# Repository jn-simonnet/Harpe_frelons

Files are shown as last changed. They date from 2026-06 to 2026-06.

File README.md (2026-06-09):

# 🐝⚡ Harpe anti-frelons asiatiques

> Conception, fabrication maison et expérimentation en conditions réelles d'une **harpe électrique anti-frelons asiatiques** — une alternative économique et durable aux dispositifs du commerce, alimentée au solaire et optionnellement connectée (LoRaWAN).

*Documentation présentée à l'atelier **Naturapi** du 27 juin 2026.*
*© J.-N. Simonnet, 2026 — Licence : [GNU GPL v3](LICENSE).*

---

## ⚡ En bref

- **Principe** : deux plans de fils inox verticaux portés à ~2 000 V. Pas de 25 mm — inférieur à l'envergure du frelon (≈ 36–40 mm), supérieur à celle de l'abeille (16 mm) : un filtre sélectif.
- **Tout au solaire, sans batterie** : ni le frelon ni l'abeille ne volent la nuit.
- **Économique** : ~200 € en autoconstruction contre 292 € à 479 € pour un kit du commerce.
- **Durable** : pièces imprimées en 3D, isolation et vernis marin soignés pour résister à la pluie et aux UV.
- **Connectée (option)** : suivi à distance de l'activité du frelon et de l'efficacité via LoRaWAN.

---

## 📖 Par où commencer

👉 **Commencez par lire [`harpe_resume-pres_naturapi.pdf`](harpe_resume-pres_naturapi.pdf).**

Ce résumé de 3 pages présente l'ensemble du projet : principe, recommandations des GDSA, fabrication, précautions d'installation et premiers résultats. Les autres documents en détaillent chacun un aspect (mécanique, électronique, support solaire, essai de terrain, nomenclature chiffrée).

---

## 📂 Contenu du dépôt

| Ordre | Fichier | Type | Description |
|:---:|---|:---:|---|
| **1** | [`harpe_resume-pres_naturapi.pdf`](harpe_resume-pres_naturapi.pdf) | PDF | **À lire en premier.** Résumé complet du projet en 3 pages (principe, GDSA, fabrication, précautions, résultats). |
| 2 | [`harpe_resume-pres_naturapi.docx`](harpe_resume-pres_naturapi.docx) | Word | Version éditable du résumé ci-dessus. |
| 3 | [`harpe_frelons-pres_Naturapi.pptx`](harpe_frelons-pres_Naturapi.pptx) | PowerPoint | La présentation complète (≈ 45 min, 24 diapositives) dont est tiré le résumé. |
| 4 | [`Design_harpe_frelons_-_mécanique.docx`](Design_harpe_frelons_-_mécanique.docx) | Word | Guide de **construction mécanique** : matériel, plans, isolateurs 3D, montage du cadre et des fils, étape par étape. |
| 5 | [`Design_harpe_frelons_-_électronique.docx`](Design_harpe_frelons_-_électronique.docx) | Word | Guide de **l'électronique** : chaîne d'alimentation solaire → DC/DC → booster 2 kV, sécurités, mesures et option objet connecté (ESP32 / LoRaWAN). |
| 6 | [`Support_pour_panneau_solaire.docx`](Support_pour_panneau_solaire.docx) | Word | Construction du **support de panneau solaire** (orientation 45° sud/sud-ouest, plan de découpe bois, connectique PV). |
| 7 | [`Essai_harpes_frelons.docx`](Essai_harpes_frelons.docx) | Word | **Compte rendu d'expérimentation** (Beaumont, octobre 2025) : dispositions testées, tableaux de capture, enseignements et suite à donner. |
| 8 | [`BOM-Naturapi.xlsx`](BOM-Naturapi.xlsx) | Excel | **Nomenclature chiffrée** (BOM) avec fournisseurs, prix et liens, plus les plans de découpe du bois et le comparatif des panneaux solaires. |
| 🖨️ | [`isolateur-arret.scad`](isolateur-arret.scad) | OpenSCAD | **Source paramétrique** de l'isolateur imprimé en 3D (pas de 25 mm, trous de passage des fils et perçages de vis, hauteur 14 mm) — modifiable pour d'autres dimensions. |
| 🖨️ | [`isolateur-arret.stl`](isolateur-arret.stl) | STL | **Maillage prêt à imprimer** de l'isolateur (export du fichier OpenSCAD), de préférence en **PETG** pour la tenue aux UV. |

---

## 🗂️ Détail des documents

### 1–2. Résumé (PDF / Word)
Synthèse de 3 pages couvrant les cinq parties du projet, un tableau comparatif des coûts et le bilan de capture sur un mois. Le PDF est le point d'entrée ; le `.docx` permet de reprendre ou d'adapter le texte.

### 3. Présentation (PowerPoint)
Le support complet de l'atelier : le principe et le système solaire, les guides des GDSA (GDSA29, GDSA21, Abeilles95) et les coûts, la conception (isolation, améliorations), la construction mécanique et électronique, les précautions d'installation et les résultats de capture.

### 4. Conception mécanique
Nomenclature pour 3 harpes (cadre 60 × 60 cm, 11 fils par plan × 2 plans, 72 isolateurs imprimés en 3D, 48 m de fil inox 0,5 mm), choix des matériaux, et les ~14 étapes de montage (vernissage, impression des isolateurs, cadre, piétement, enfilage et mise en tension des fils, chapeau anti-pluie).

### 5. Conception électronique
Schéma d'alimentation (panneau solaire → 2 convertisseurs DC/DC → booster 2 kV + condensateur 470 nF/2 kV), sécurités (coupure rapide de la HT, protection contre les courts-circuits), et l'option objet connecté (mesure de la HT, de la tension solaire, de la température, comptage des électrocutions, transmission LoRaWAN).

### 6. Support de panneau solaire
Construction d'un support en planches de coffrage sur piquet, orienté à 45° sud/sud-ouest pour maximiser la production à l'automne (période d'activité des frelons), avec plan de découpe et connectique photovoltaïque standard.

### 7. Essai de terrain
Retour d'expérience d'octobre 2025 : contexte d'infestation, dispositions successives des harpes, tableaux de comptage (frelons, abeilles, autres insectes) par piège et par harpe, et les enseignements clés — notamment la position optimale de la harpe centrale et la limitation des captures d'abeilles.

### 8. Nomenclature (BOM)
Classeur Excel à plusieurs feuilles : nomenclature détaillée avec fournisseurs, prix et liens d'achat (≈ 242 € de matériel, panneau et support compris) ; plan de découpe des tasseaux ; comparatif de panneaux solaires (12 → 60 W) ; matériel et découpe du support de panneau.

### 🖨️ Pièce imprimée en 3D — l'isolateur
`isolateur-arret.scad` (source **OpenSCAD** paramétrique) et `isolateur-arret.stl` (maillage exporté, prêt à imprimer) définissent l'isolateur qui supporte et espace les fils inox. Juxtaposés, ces isolateurs forment les barres transversales isolantes de la harpe : pas de 25 mm entre fils, deux plans de fils espacés de 2,5 mm, et deux trous de vis pour la fixation sur les joues en bois. À imprimer de préférence en **PETG** (durabilité aux UV) ; il en faut **24 par harpe (72 pour 3 harpes)**. Le fichier `.scad` permet d'ajuster facilement le pas ou les dimensions.

---

## 🔧 Ordre de lecture conseillé

1. **`harpe_resume-pres_naturapi.pdf`** — pour comprendre le projet d'ensemble.
2. **`harpe_frelons-pres_Naturapi.pptx`** — pour une vue détaillée et illustrée.
3. **`Design_harpe_frelons_-_mécanique.docx`** puis **`...-_électronique.docx`** — pour fabriquer (imprimez au préalable les isolateurs à partir de **`isolateur-arret.stl`**).
4. **`Support_pour_panneau_solaire.docx`** — pour l'alimentation solaire.
5. **`Essai_harpes_frelons.docx`** — pour les résultats et les bonnes pratiques d'installation.
6. **`BOM-Naturapi.xlsx`** — pour s'approvisionner et chiffrer le projet.

---

## ⚠️ Avertissement — sécurité électrique

Ce dispositif fonctionne sous **haute tension (≈ 2 000 V)**. Le contact est dangereux : couper l'alimentation et attendre la décharge complète avant toute manipulation, signaler l'installation par un panneau « Danger Haute Tension », et la tenir hors de portée des enfants et des animaux.

> Il s'agit d'un **matériel non certifié et non commercialisé**. Quiconque entreprend sa construction à partir de cette documentation en assume l'entière responsabilité en cas d'accident ou de dommage lié à sa fabrication, son installation ou son utilisation (y compris d'incendie).

**Précaution apicole :** ne jamais installer une harpe près d'une ruche ou ruchette contenant un essaim récent — la reine vierge, d'envergure comparable à celle du frelon, n'a pas encore fait son vol de fécondation et risquerait d'être électrocutée.

---

## 📜 Licence & contact

**Tous les fichiers de ce dépôt** (documents, présentation, modèles 3D, nomenclature) sont publiés sous licence **GNU Affero General Public License v3.0 (AGPL v3)**.

Vous êtes libre de les utiliser, les modifier et les redistribuer — y compris à des fins commerciales — à condition de conserver cette licence et d'en créditer l'auteur ; toute œuvre dérivée doit être distribuée sous la même licence **GPL v3**. Le projet est fourni **sans aucune garantie**, dans la mesure permise par la loi.

Le texte complet de la licence doit accompagner le dépôt dans un fichier [`LICENSE`](LICENSE) — voir aussi <https://www.gnu.org/licenses/gpl-3.0.html>.

Conception et documentation : **© J.-N. Simonnet, 2026**.

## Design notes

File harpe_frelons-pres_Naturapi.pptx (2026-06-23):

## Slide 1

APICULTURE · LUTTE BIOLOGIQUE

La harpe
anti-frelons asiatiques

Principe · recommandations des GDSA · fabrication maison

Présentation pour l’atelier Naturapi du 27/6/2026

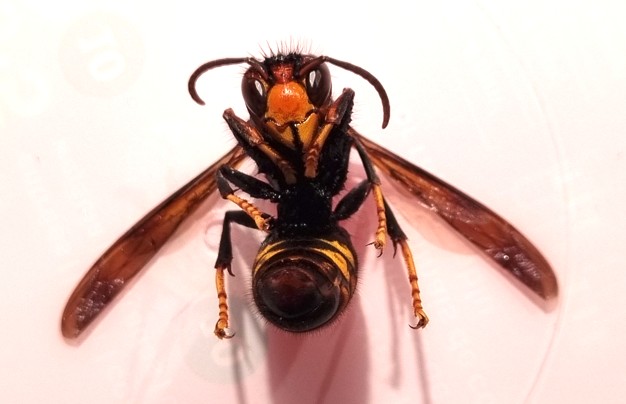
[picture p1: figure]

Présentation ~45 min

© J.N. Simonnet - 2026

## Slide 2

Sommaire

Le principe

Fils sous haute tension, géométrie sélective, système complet

1

2

Les recommandations des GDSA

Guides GDSA29, GDSA21, Abeilles95 — design conseillé & coûts

3

Précautions d’installation

Là où la harpe peut être contre-productive et comment l’améliorer

4

Résultats de capture

Premiers comptages en conditions réelles, à Beaumont (63)

5

Fabriquer soi-même

Améliorations, isolation, construction mécanique & électronique

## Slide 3

1

PARTIE 1

Le principe

Comment une harpe électrique cible le frelon en épargnant l'abeille

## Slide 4

PARTIE 1 · LE PRINCIPE

Un filtre électrique sélectif

Des fils verticaux sous 2000 V

Deux plans de fils inox tendus, portés à haute tension. Le frelon qui les touche ferme le circuit.

Un pas calculé : 25 mm

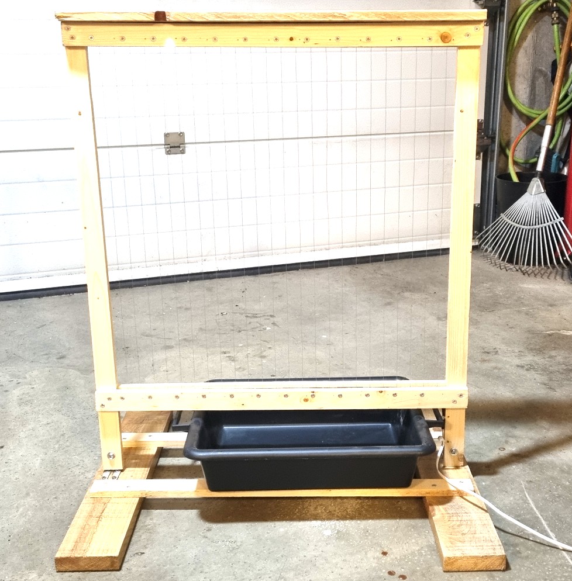
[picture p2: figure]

Harpe montée sur piétement, bac à eau dessous

Inférieur à l'envergure du frelon asiatique (≈ 36–40 mm), mais supérieur à celle de l'abeille (16 mm) : l'abeille passe, le frelon non (ça, c’est la théorie !).

La décharge

Au contact des ailes, la décharge paralyse ou détruit les muscles de vol selon l'énergie appliquée.

Le bac à eau

Sous la harpe, un bac d'eau additionnée de liquide vaisselle noie le frelon étourdi (mouille les ailes à coup sûr).

Harpe anti-frelons asiatiques - © J.N. Simonnet - 2026

1 / 17

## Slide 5

PARTIE 1 · LE PRINCIPE

Le système complet : tout au solaire

Panneau
solaire

→

Régulateur
DC/DC

→

Générateur
HT 2 kV

→

3 harpes
(pour 5 ruches)

Pas de batterie

Ni le frelon ni l'abeille ne volent la nuit : inutile d'alimenter la HT après le coucher du soleil. Supprimer la batterie réduit le coût et simplifie grandement l'entretien (pas de recharge de la batterie).

Positionnement

Harpes placées parallèlement aux côtés de la ruche : elles interceptent les frelons qui arrivent par le flanc pour saisir les abeilles devant la planche d'envol.

Harpe anti-frelons asiatiques - © J.N. Simonnet - 2026

2 / 17

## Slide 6

2

PARTIE 2

Les recommandations des GDSA

Ce que conseillent les Groupements de Défense Sanitaire Apicole

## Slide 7

PARTIE 2 · GDSA

Trois guides de référence en ligne

GDSA 29

Finistère

gdsa29.fr

GDSA 21

Côte-d'Or

gdsa21.fr

Abeilles 95

Val-d'Oise

abeilles95.fr

Propose un kit. Pas entre fils de 24 mm, montage sans ressorts. Montage avec isolateurs. Electrocution du frelon qui tombe dans un bac d’eau

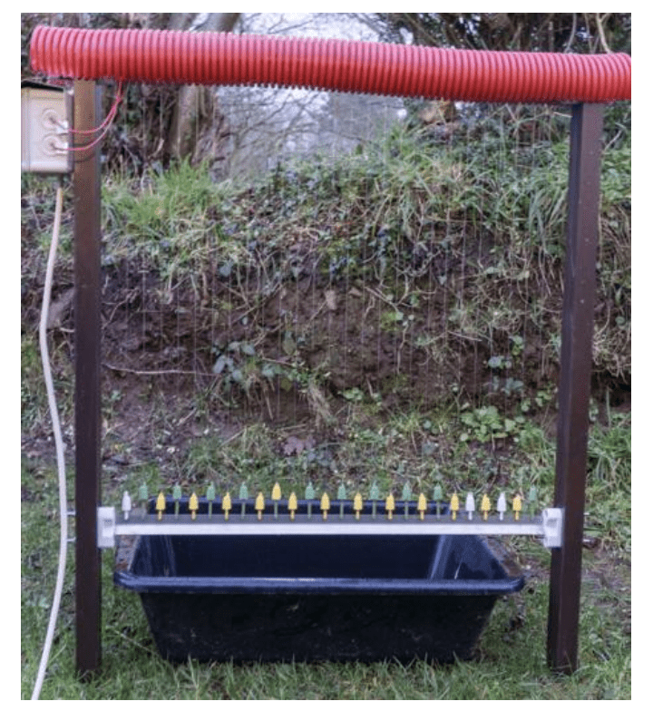
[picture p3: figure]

Tréteaux + réglettes plastique percées + ressorts. Tension 1800V, puis kit commercial.
Pas des fils 26–29 mm, ressorts inox pour la tension, module HT ~1800 V, condensateur pour meilleure efficacité

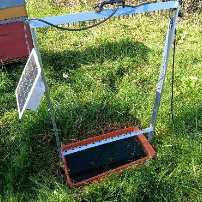
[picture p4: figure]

Version initiale à base de gaines électriques (pas de 24 mm), puis base tréteau + punaises pour tableau de liège ou pièces imprimées en 3D. HT utilisant le même module que ma réalisation.

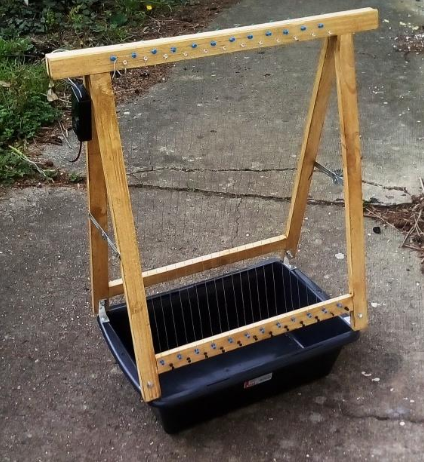
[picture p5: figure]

Conception conseillée par les GDSA : fils espacés de 24–29 mm · ~1800–2000 V continu · bac à eau · protection pluie (dessus + côtés)

Harpe anti-frelons asiatiques - © J.N. Simonnet - 2026

3 / 17

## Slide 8

PARTIE 2 · GDSA

Limites connues & coût des solutions

Les limites identifiées

La pluie est l'ennemi principal : l'humidité crée des fuites et fait s'écrouler la HT. Porter de l’attention à la protection du bois et à l’isolation

Acheter ou fabriquer ?

Autoconstruction (GDSA + réglettes Naturapi)

3 harpes châssis bois + électronique + panneau solaire 50W + barrette isolation

~ 200 €

Les gaines plastiques se dégradent aux UV : poreuses au bout d'une saison → perte d'isolation.

Le matériel (panneaux, batteries) peut attirer les voleurs dans les ruchers isolés.

Kit SANVE (3 harpes + élec.)

site espagnol, panneau solaire

580 €

Porter attention à la tension des fils inox (ne pas passer 1 seul fil, mais tendre des fils individuels connectés, risque de casse), idéalement utiliser des ressorts

Kit 3 harpes NaturAPI

3 harpes châssis alu montées + électronique + panneau solaire 20W

479 €

Panneau solaire: perte de puissance significative par temps couvert, il est nécessaire de surdimensionner sa puissance

La fabrication des harpes reste simple : à la portée de tout bricoleur expérimenté (mécanique + électronique simple).
Environ 1 semaine de travail (temps de séchage vernis compris) + délai de commande ~10J pour l’électronique

Harpe anti-frelons asiatiques - © J.N. Simonnet - 2026

4 / 17

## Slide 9

3

PARTIE 3

Précautions d'installation

Là où la harpe peut nuire — et comment l'éviter

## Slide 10

PRÉCAUTIONS D'INSTALLATION

Le point d'attention majeur

⚠ Ne jamais utiliser pour une ruche ou ruchette contenant un essaim artificiel récent

La reine vierge n'a pas encore fait son vol de fécondation. Son envergure est comparable à celle du frelon asiatique.

Bonnes règles de placement

1

Une harpe pour 5 ruches

aux extrémités d'un alignement, perpendiculaire à la ligne de ruches.

3

Parallèle au flanc des ruches

pour intercepter les frelons qui arrivent par le côté, devant la planche d'envol.

2

Utiliser harpes et pièges

un couloir de grillage à ~1 m devant les ruches peut être utile pour oriente leur vol vers la harpe.

4

Entretenir régulièrement

retirer souvent les frelons ; signaler la zone par un panneau « Danger Haute Tension ».

Harpe anti-frelons asiatiques - © J.N. Simonnet - 2026

12 / 17

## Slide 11

PRÉCAUTIONS D'INSTALLATION

Le choix du bac est critique

Sous la harpe, le liquide du bac noie le frelon étourdi — mais un mauvais choix piège aussi les abeilles. Retour d'expérience (octobre 2025) :

≈ 50 abeilles noyées dès le lendemain (venues boire).

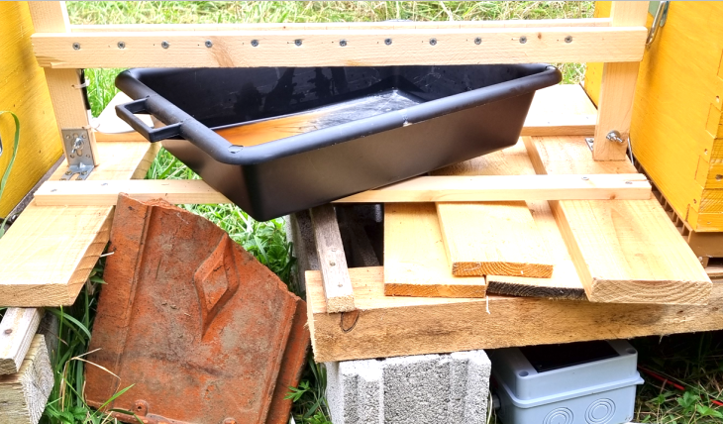
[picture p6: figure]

Eau pure

À ÉVITER

Encore une dizaine d'abeilles engluées.

Huile

INSUFFISANT

Limite fortement — sans supprimer totalement — les captures d'abeilles.

Eau + liquide vaisselle

RECOMMANDÉ

À retenir préférer un produit non parfumé (savon glycériné type vaisselle Palmolive) ; ne pas placer la harpe sur le passage des abeilles.

Harpe anti-frelons asiatiques - © J.N. Simonnet - 2026

13 / 17

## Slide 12

4

PARTIE 4 · EXPÉRIMENTATION — OCTOBRE 2025

Résultats de capture

Premiers comptages en conditions réelles, à Beaumont (63)

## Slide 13

PARTIE 4 · RÉSULTATS

L'expérimentation en conditions réelles

Pourquoi cet essai ?

En octobre 2024, l'infestation à Beaumont (63) était très forte : malgré la destruction d'un nid à 100 m, les frelons ont envahi et détruit une colonie le 8 novembre. En octobre 2025, pression encore significative (~60 frelons/semaine sur 2 pièges) — d'où l'essai des harpes.

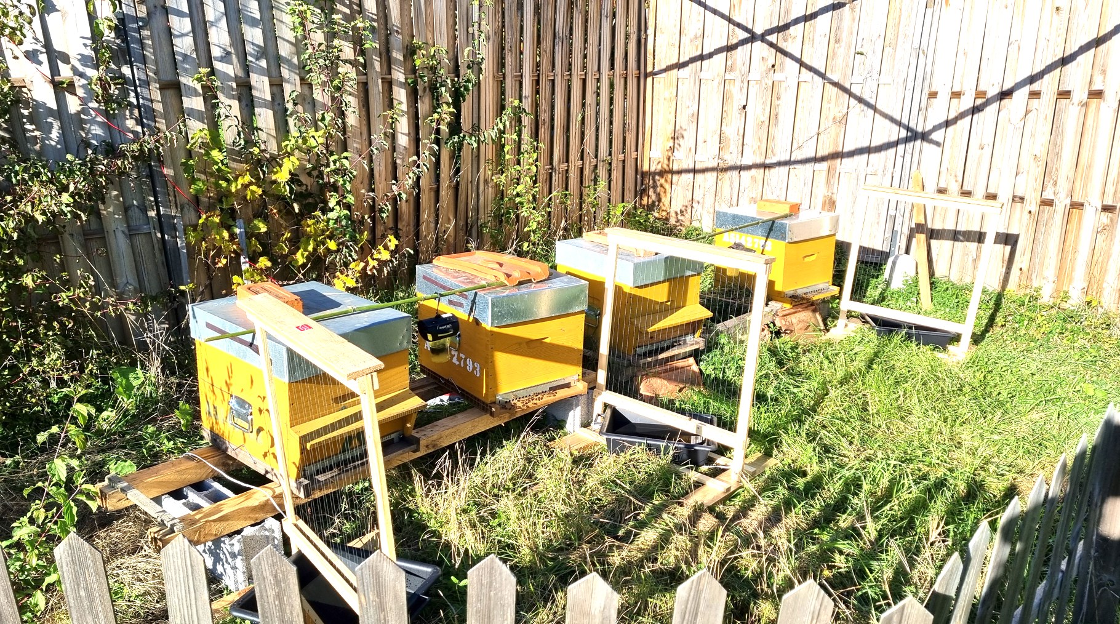
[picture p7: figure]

Les trois harpes en action devant le rucher

Ce que dit le plan national de lutte

Harpes en complément des muselières et restrictions d'entrée.

Le stress des colonies disparaît ~8 jours après la mise en place.

Une harpe pour 5 ruches, aux extrémités de l'alignement.

Efficacité : jusqu'à 200 frelons capturés par jour.

Harpe anti-frelons asiatiques - © J.N. Simonnet - 2026

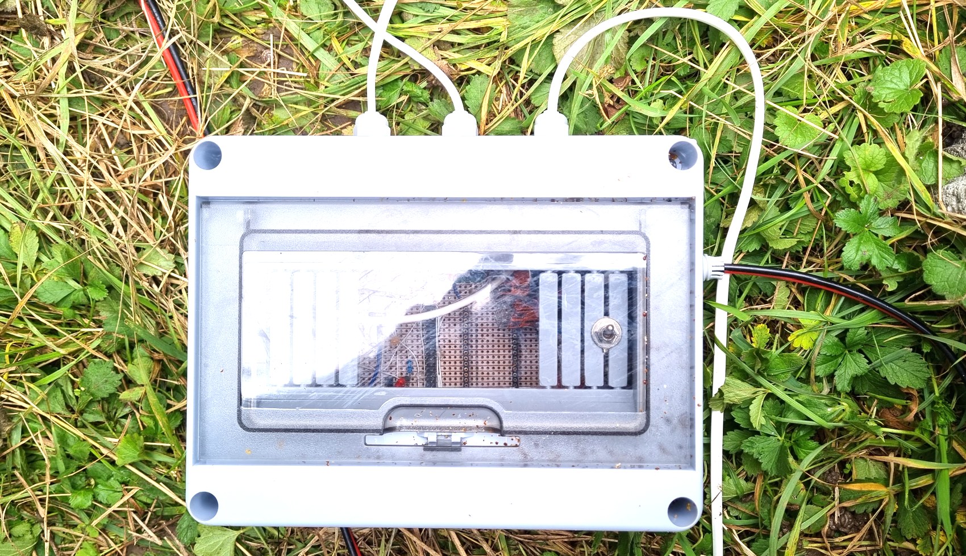
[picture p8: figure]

Le boîtier électronique installé et raccordé

14 / 17

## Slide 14

PARTIE 4 · RÉSULTATS

Bilan de capture sur un mois

Date | Période (jours) | Sur la période | | | Captures journalières
| | Pièges | Harpes | Abeilles | Pièges | Harpes | Abeilles
07 oct — Installation des harpes
07 oct | 7 | 64 | n/a | n/a | 9,1 | n/a | n/a
11 oct | 4 | 20 | 9 | n/a | 5,0 | 2,3 | n/a
13 oct | 2 | 36 | 17 | 224 | 18,0 | 8,5 | 112,0
06 nov | 24 | 44 | 26 | 258 | 1,8 | 1,1 | 10,8
06 nov — Intervention : destruction d'un nid à 100 m

216

frelons capturés en un mois

Harpe anti-frelons asiatiques - © J.N. Simonnet - 2026

× 2

les pièges capturent 2× plus que les harpes (attention, il y a eu des arrêts de fonctionnement du fait d’un panneau solaire insuffisant)

12 W

panneau sous-dimensionné : harpes à l'arrêt par temps couvert

15 / 17

Période marquée par de nombreux jours de pluie / temps couvert : efficacité non maximale.

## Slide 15

PARTIE 4 · RÉSULTATS

Captures détaillées sur une semaine

Insecte | Pièges | | Harpes
| Gauche | Droite | Gauche | Milieu | Droite
Frelons asiatiques | 26 | 10 | 6 | 6 | 5
Frelons européens | 1 | – | – | – | –
Abeilles | 2 | 2 | 128 | 38 | 58
Faux-bourdons | – | – | 2 | 1 | 2
Guêpes | 3 | 5 | 1 | – | 2
Sauterelle / cloportes | – | – | – | – | 1 / 2

Harpe droite : 1 fondatrice capturée (corps 35 mm, envergure 40 mm).

Ce que révèlent ces chiffres

La harpe du milieu

capture le plus de frelons et le moins d'abeilles : la meilleure position.

Trop d'abeilles capturées

128 sur la seule harpe de gauche : elle est trop proche de l'entrée de la ruche.

Les pièges restent utiles

ils captent ici plus de frelons que les harpes sur la même semaine.

Harpe anti-frelons asiatiques - © J.N. Simonnet - 2026

16 / 17

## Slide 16

PARTIE 4 · RÉSULTATS

Enseignements & suite à donner

Ce que l'on retient

Les abeilles traversent les harpes, mais certaines heurtent les fils et chutent, assommées, dans le bac.

Pic d'abeilles le 6/11 sur la harpe de gauche (proche de l'entrée) : possible mortalité d'abeilles d'été rendue visible.

Météo limitante : pluie et temps couvert + panneau 12 W → harpes souvent non alimentées.

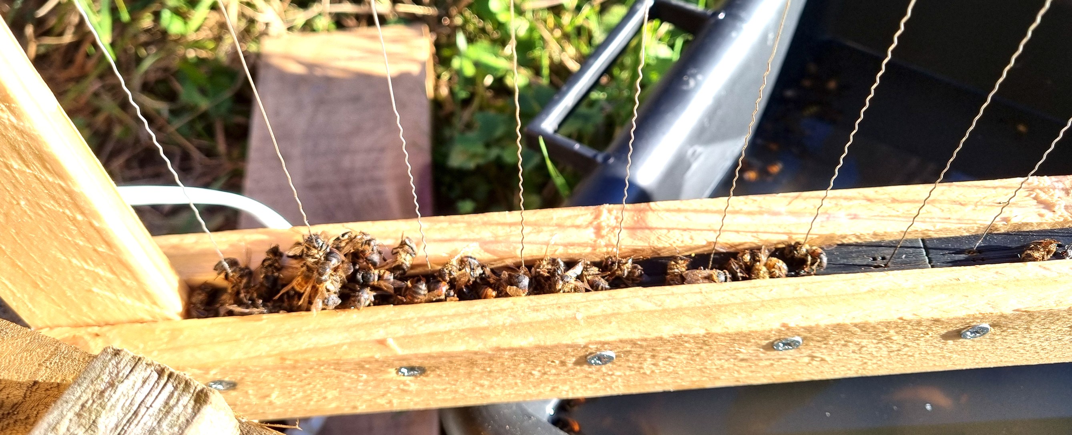
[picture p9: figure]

Accumulation d'abeilles sur la harpe de gauche (6 nov.)

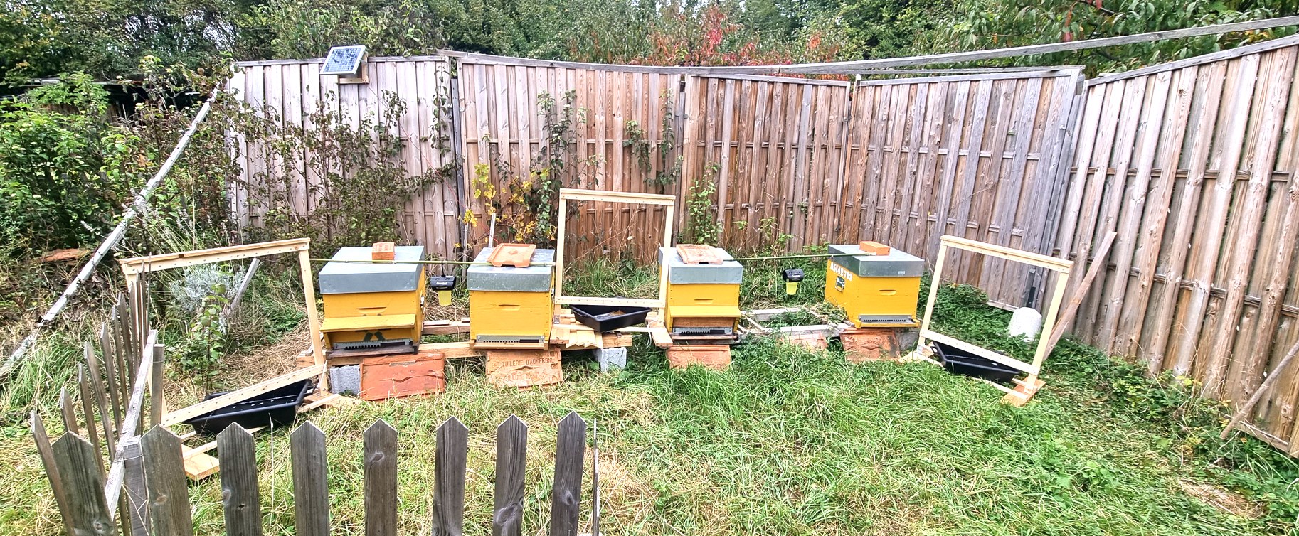
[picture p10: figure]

Nouvelle disposition : harpe centrale dégagée, barrière rapprochée

Suite à donner

Écarter les ruches de gauche · produit non parfumé (savon glycériné) · dégager la harpe centrale et rapprocher la barrière · filmer pour vérifier l'hypothèse · tester une harpe horizontale sous le plancher.

Harpe anti-frelons asiatiques - © J.N. Simonnet - 2026

17 / 17

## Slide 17

5

PARTIE 5

Fabriquer soi-même

Critères de conception, points d'attention et réalisation

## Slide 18

PARTIE 3 · CONCEPTION

Le point d'attention n°1 : l'isolation

Une isolation irréprochable conditionne un fonctionnement durable — surtout après la pluie : le bois mouillé met des heures à sécher et fait s’écrouler la HT pendant ce temps.

≈ 4 Ω

Résistance d'un pont de bois mouillé (2,5 cm) — suffit à écrouler la HT

2,5 mm

Écart entre plans de fils — l'air sec (3 kV/mm) isole largement les 2 kV

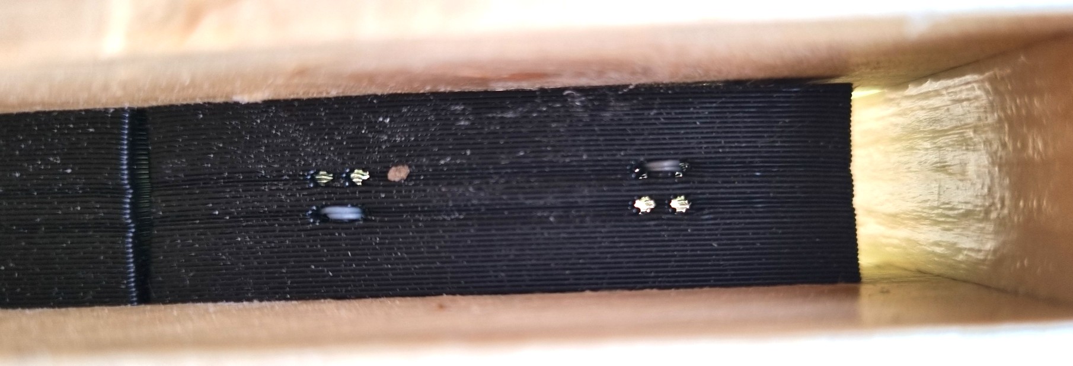
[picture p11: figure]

Les mesures prises

Pièces plastique partout où le bois toucherait les fils

≥ 3 couches de vernis marin sur tout le bois (durabilité + isolation)

Manchons thermo-rétractables là où les fils sont proches

Chapeau anti-pluie + pas d'accumulation d'eau (évaporation rapide)

Harpe anti-frelons asiatiques - © J.N. Simonnet - 2026

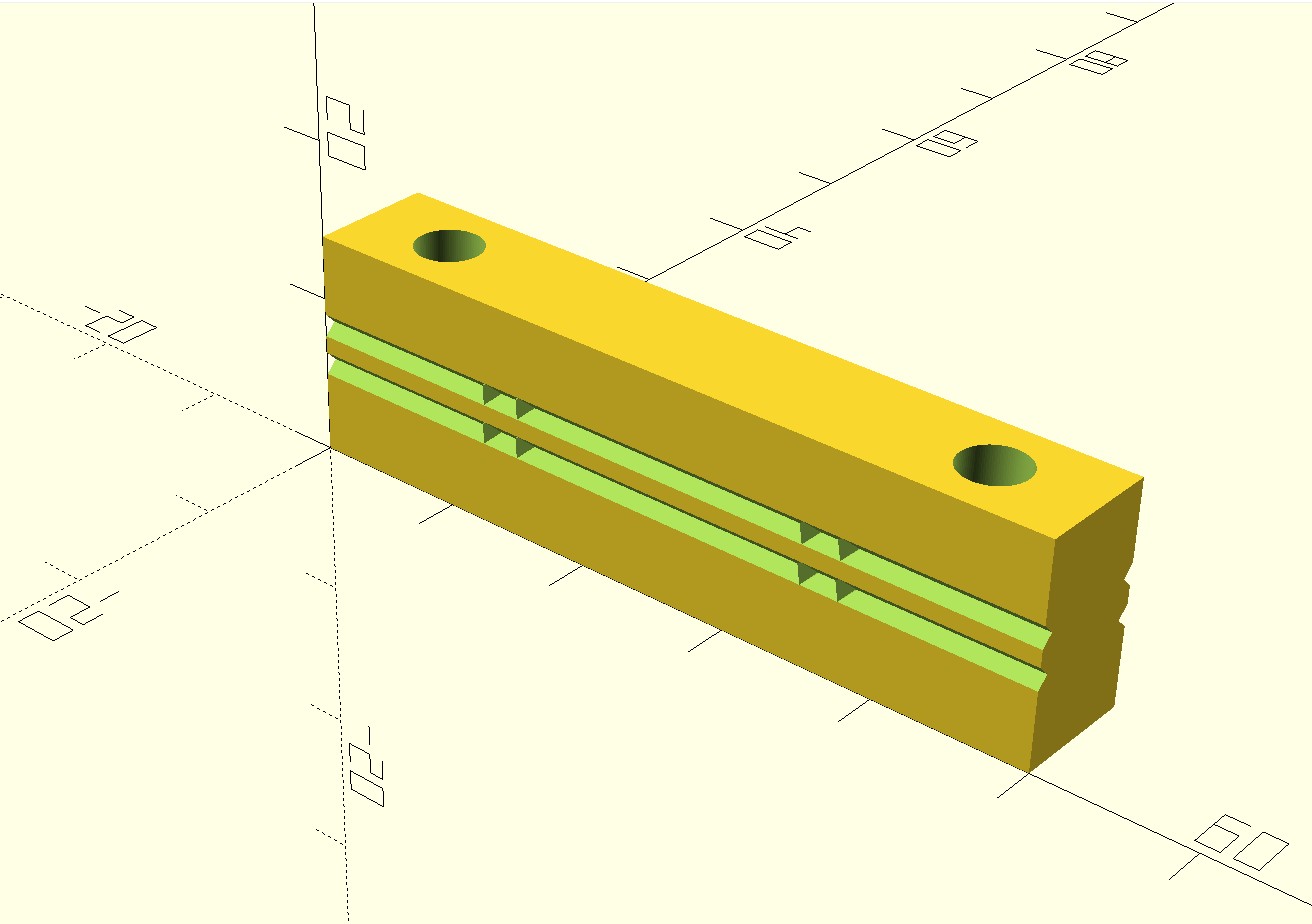
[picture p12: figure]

Barre transversale isolée · isolateur imprimé en 3D

5 / 17

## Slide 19

PARTIE 3 · CONCEPTION

Mes améliorations sur le design d'origine

Pièces imprimées en 3D

Espacement précis (±0,5 mm) et durabilité : fini la gaine annelée détruite par les UV.

Sécurité court-circuit

Un court-circuit détruisait le condensateur 100 nF → simple étourdissement. Protection ajoutée.

Coupure rapide de la HT

Sans elle, la HT subsiste 2–3 min après l'arrêt (décharge du condensateur) : risque opérateur.

1

2

3

Mesure de la HT

Détecte les déclenchements et, comparée au bac à eau, mesure l'efficacité du dispositif.

4

Condensateur 470 nF / 2 kV

Augmente l'énergie de décharge : tue le frelon au lieu de seulement l'étourdir.

5

Objet connecté (LoRaWAN)

Suivi de l'activité du frelon dans le temps et de l'efficacité, à distance.

6

Harpe anti-frelons asiatiques - © J.N. Simonnet - 2026

6 / 17

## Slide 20

PARTIE 3 · MÉCANIQUE

Construire les harpes : l'essentiel

3

harpes pour 5 ruches

72

isolateurs 3D (24/harpe)

48 m

de fil inox 0,5 mm

3 j

de travail (séchage vernis)

Matériel principal (3 harpes)

8 tasseaux bois 15×38 mm + planchettes chapeau + planches piétement

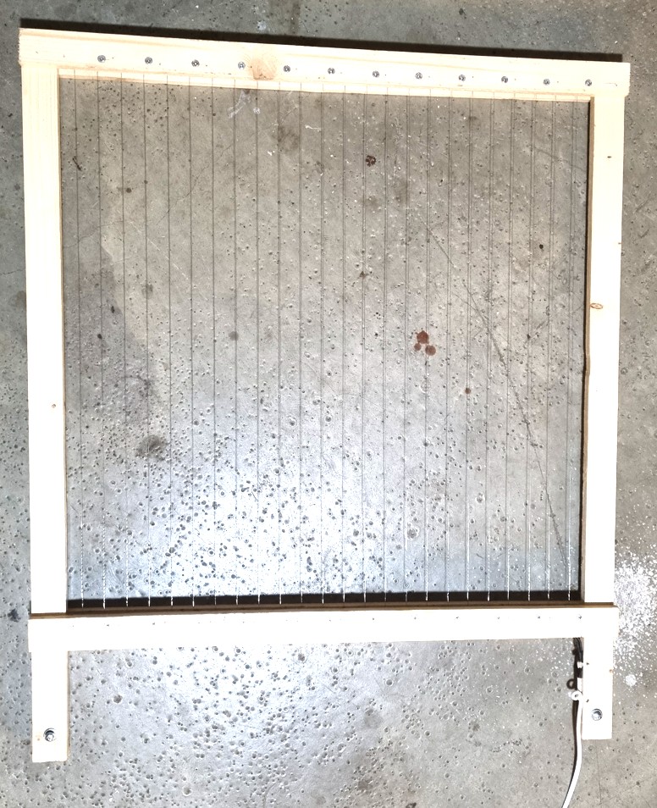
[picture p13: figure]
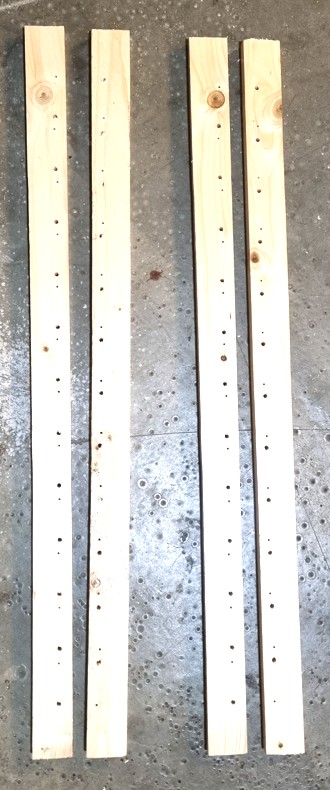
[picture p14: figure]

Fil inox 0,5 mm, équerres galva, vis ; câble souple 2G0,75 (HT)

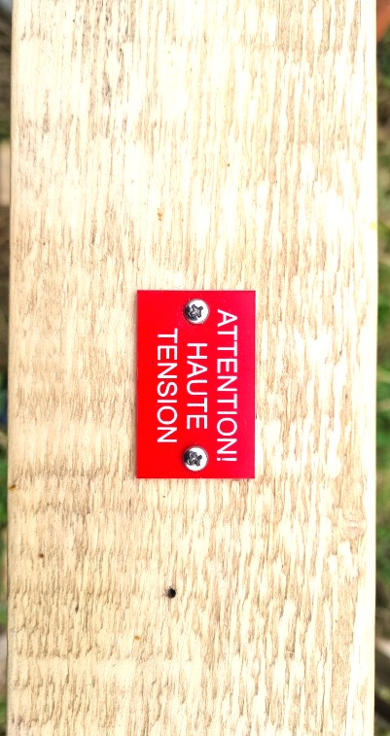
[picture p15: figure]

7 / 17

72 isolateurs imprimés 3D + gaines thermo-rétractables

Vernis marin, plaques « Danger Haute Tension », connecteurs étanches

Cadre 60 × 60 cm · 11 fils par plan × 2 plans · 14 étapes : vernir, imprimer les isolateurs, monter le cadre & le piétement, enfiler puis tendre les fils, poser le chapeau.

Harpe anti-frelons asiatiques - © J.N. Simonnet - 2026

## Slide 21

PARTIE 3 · MÉCANIQUE

La réalisation en images

Assemblage du cadre

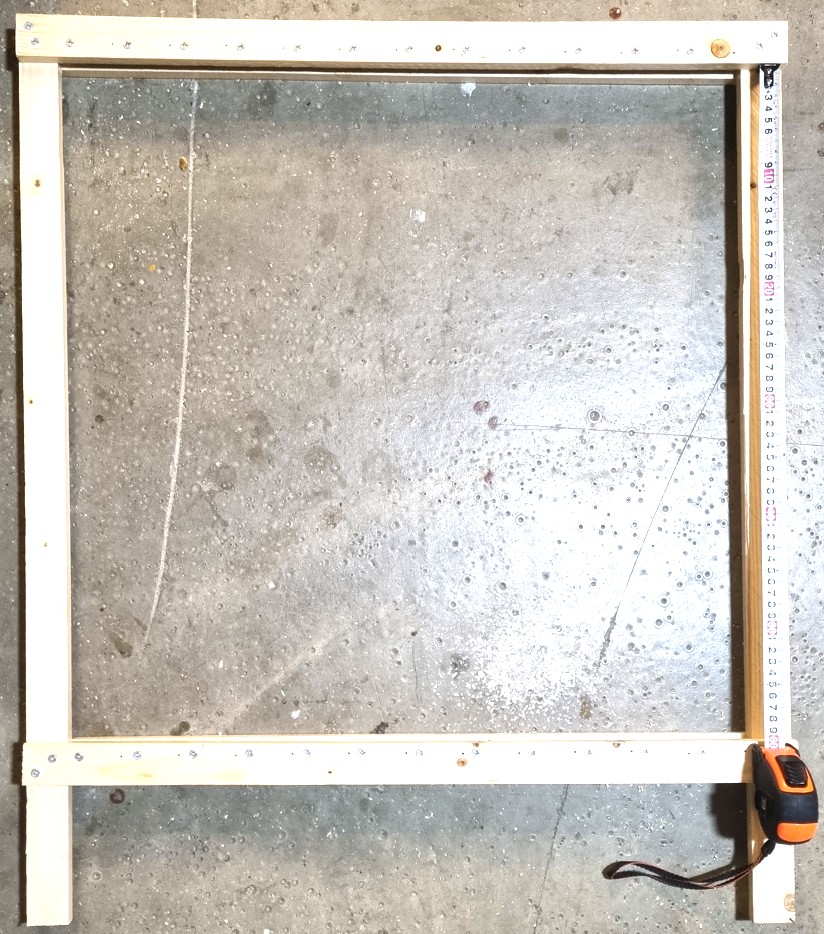
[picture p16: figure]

Barre + isolateurs 3D

Plan : passage des fils HT+/HT−

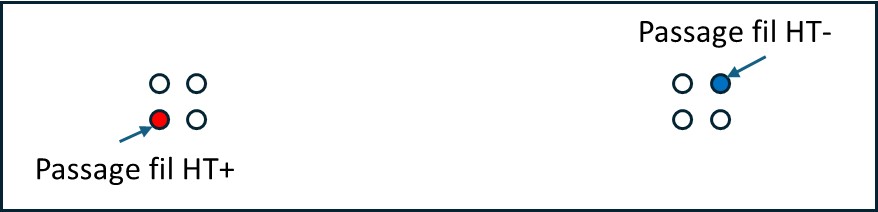
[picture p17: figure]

Connecteurs étanches

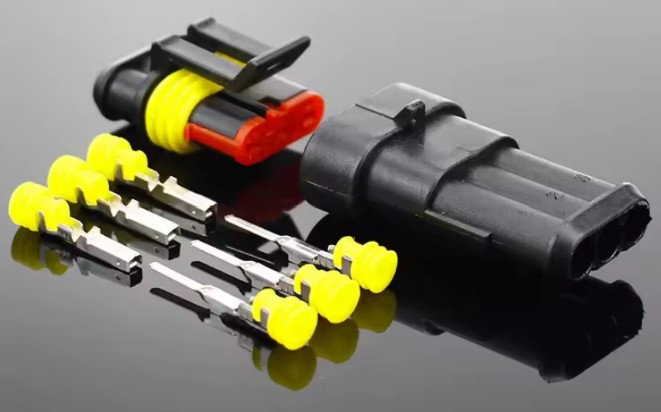
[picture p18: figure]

Plaque d'avertissement

Harpe complète + bac à eau

Harpe anti-frelons asiatiques - © J.N. Simonnet - 2026

8 / 17

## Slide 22

PARTIE 3 · ÉLECTRONIQUE

L'électronique : la version de base

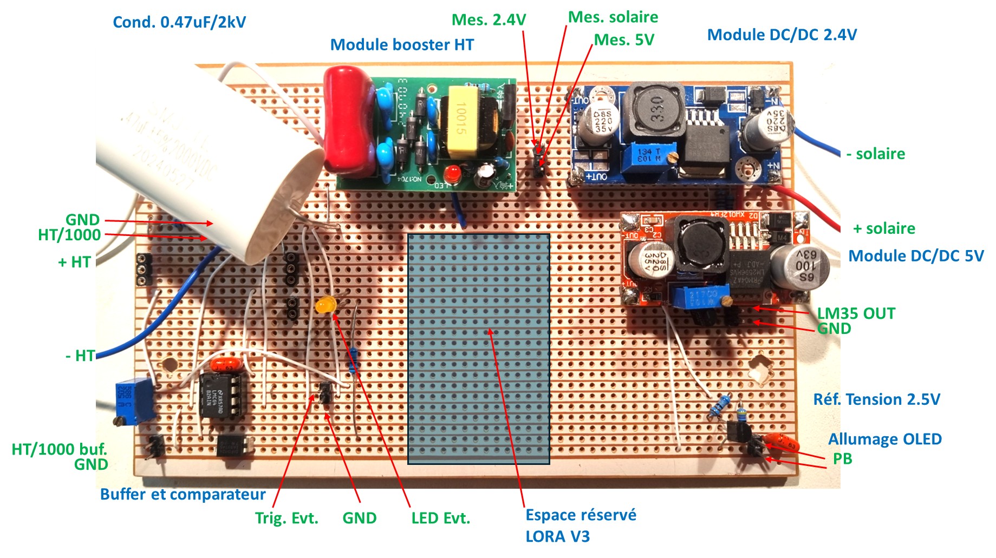
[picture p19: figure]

Prototype annoté : modules d'alimentation, booster HT et conditionnement du signal

La chaîne d'alimentation

Panneau solaire

« 50 W » → 2 convertisseurs DC/DC

DC/DC LM2596

2,4 V (booster) et 5 V (électronique)

Booster 2 kV

la haute tension alimentant les harpes

Condensateur 470 nF/2 kV

plus d'énergie : électrocute le frelon

Sécurité opérateur

Coupure rapide de la HT à l'arrêt (relais, thyristor ou MOSFET/IGBT) + protection du condensateur de sortie contre les courts-circuits.

Harpe anti-frelons asiatiques - © J.N. Simonnet - 2026

9 / 17

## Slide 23

PARTIE 3 · ÉLECTRONIQUE

Choix du panneau & objet connecté

Dimensionnement du panneau solaire

Attention au matériels vendus en ligne : un panneau de 25 x 25 cm ne peut pas délivrer 50W, mais tout au plus 10W.
Nécessité de le surdimensionner (40 W minimum), car par temps couvert, la puissance peut tomber à 20% seulement.

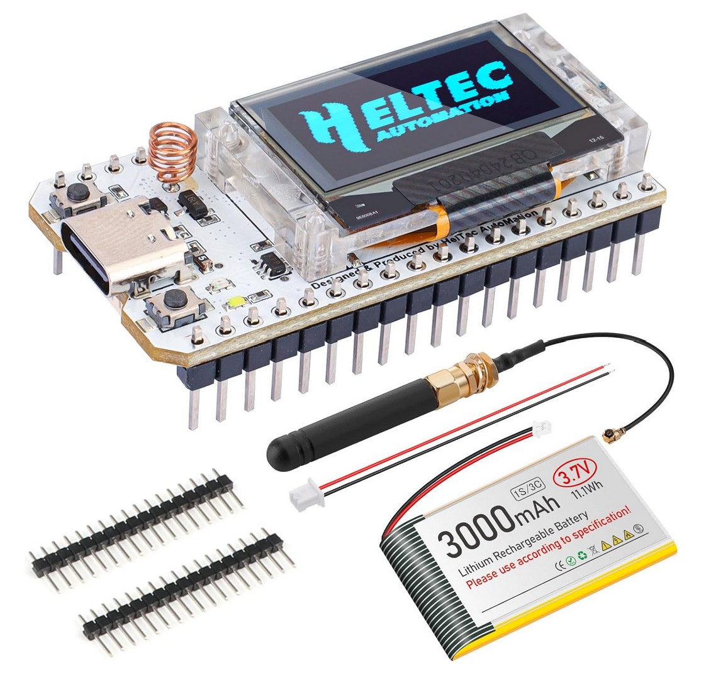
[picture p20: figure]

ESP32 LORA32 V3 (LoRaWAN SX1262)

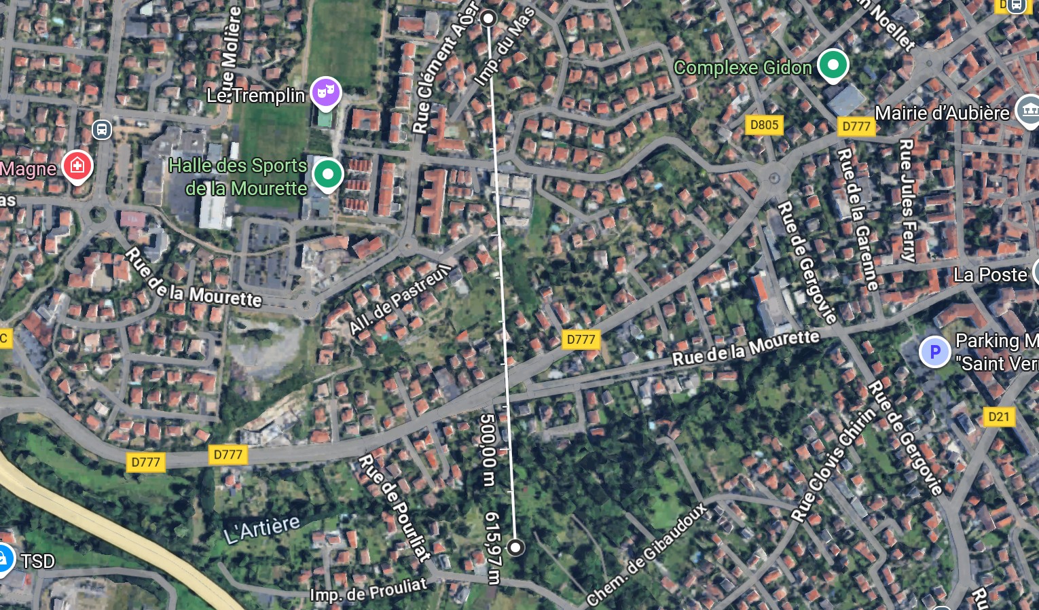
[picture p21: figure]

Portée gateway ≈ 2,5 km

Ce que mesure l'objet connecté

Haute tension (détection des déclenchements < 1500 V)

Tension du panneau solaire (jour/nuit, ensoleillement)

Tensions d'alimentation + température (LM35)

Comptage des électrocutions (interruption + compteur journalier)

Le bénéfice

Connaître l'activité du frelon heure par heure et au fil des mois, et mesurer l'efficacité réelle (électrocutions comptées vs frelons dans le bac) — sans se déplacer, via le réseau collaboratif LoRaWAN.

Harpe anti-frelons asiatiques - © J.N. Simonnet - 2026

10 / 17

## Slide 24

Une isolation irréprochable conditionne un fonctionnement durable — surtout après la pluie : le bois mouillé met des heures à sécher et fait fuir la HT pendant ce temps.

PARTIE 3 · BOM

Détail du coût de construction

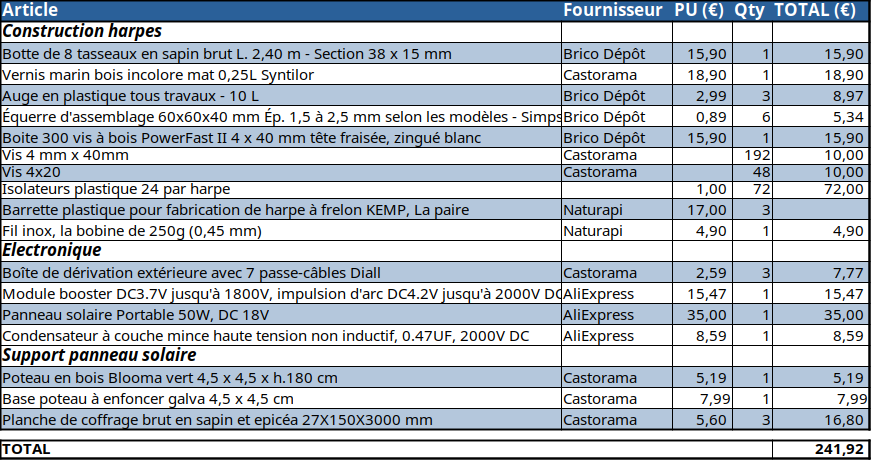
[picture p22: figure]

L’option originelle (fabrication additive des isolateurs) est légèrement plus chère que l’utilisation des barrettes KEMP (Naturapi). Avec barrettes Kemp, utiliser des tréteaux à 16€ (Castorama), mais il reste nécessaire de les vernir à 3 couches de vernis marin

Harpe anti-frelons asiatiques - © J.N. Simonnet - 2026

11 / 17

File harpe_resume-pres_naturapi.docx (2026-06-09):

APICULTURE · LUTTE BIOLOGIQUE

La harpe anti-frelons asiatiques

Résumé de la présentation — principe, recommandations des GDSA et fabrication maison

Atelier Naturapi du 27 juin 2026 · © J.-N. Simonnet, 2026

La harpe électrique est un dispositif placé devant les ruches pour électrocuter les frelons asiatiques tout en laissant passer les abeilles. Ce résumé en présente le principe, les recommandations des GDSA, la fabrication maison, les précautions d’installation et les premiers résultats obtenus en conditions réelles.

# 1. Le principe

Deux plans de fils inox verticaux sont tendus puis portés à environ 2 000 V. Le frelon qui touche deux fils ferme le circuit et reçoit une décharge qui, au contact des ailes, paralyse ou détruit ses muscles de vol.

- Un filtre sélectif : le pas des fils (25 mm) est inférieur à l’envergure du frelon (≈ 36–40 mm) mais supérieur à celle de l’abeille (16 mm) : l’abeille passe, le frelon non.
- Le bac à eau : sous la harpe, un bac d’eau additionnée de liquide vaisselle noie le frelon étourdi (et mouille ses ailes à coup sûr).
- Système tout-solaire : panneau solaire → régulateur DC/DC → générateur HT 2 kV → 3 harpes pour 5 ruches. Pas de batterie : ni le frelon ni l’abeille ne volent la nuit — d’où une économie et un entretien simplifié.

# 2. Les recommandations des GDSA

Trois groupements diffusent des guides de construction en ligne. Leur conception conseillée converge : fils espacés de 24–29 mm, tension continue de 1 800–2 000 V, bac à eau, et protection contre la pluie (dessus et côtés).

- GDSA 29 (Finistère) : kit proposé, pas entre fils de 24 mm sans ressorts, montage avec isolateurs, frelon électrocuté tombant dans un bac d’eau.
- GDSA 21 (Côte-d’Or) : tréteaux + réglettes plastique percées + ressorts inox, module HT ~1 800 V, condensateur pour une meilleure efficacité, pas entre fils de 26–29 mm.
- Abeilles 95 (Val-d’Oise) : version initiale à gaines électriques puis base tréteau avec punaises ou pièces imprimées en 3D ; même module HT que la réalisation présentée.

Limites connues : la pluie est l’ennemi principal (l’humidité crée des fuites et fait s’écrouler la HT) ; les gaines plastiques se dégradent aux UV ; le matériel peut attirer les voleurs ; il faut soigner la tension des fils (fils individuels, idéalement avec ressorts) et surdimensionner le panneau solaire, dont la puissance chute par temps couvert.

Acheter ou fabriquer ? La fabrication des harpes reste à la portée d’un bricoleur expérimenté (mécanique + électronique simple), pour environ une semaine de travail (séchage du vernis compris) et un délai de commande d’environ 10 jours pour l’électronique.

Solution | Composition | Coût indicatif
Autoconstruction (GDSA + réglettes Naturapi) | 3 harpes châssis bois + électronique + panneau 50 W + barrette d’isolation | ~ 200 €
Kit SANVE (3 harpes + électronique) | Site espagnol, avec panneau solaire | 292 €
Kit 3 harpes NaturAPI | Châssis alu montés + électronique + panneau 20 W | 479 €

# 3. Fabriquer soi-même

## L’isolation, point d’attention n°1

Une isolation irréprochable conditionne la durabilité, surtout après la pluie : le bois mouillé (≈ 4 Ω sur 2,5 cm) suffit à écrouler la HT, alors que l’air sec isole largement 2 kV sur 2,5 mm. Mesures retenues : pièces plastique partout où le bois toucherait les fils, au moins 3 couches de vernis marin, manchons thermo-rétractables, et un chapeau anti-pluie évitant toute accumulation d’eau.

## Mes améliorations sur le design d’origine

- Pièces imprimées en 3D : espacement précis (±0,5 mm) et durabilité (fini la gaine annelée détruite par les UV).
- Sécurité court-circuit : protège le condensateur 100 nF, dont la destruction réduisait la décharge à un simple étourdissement.
- Coupure rapide de la HT : sans elle, la HT subsiste 2–3 min après l’arrêt : risque pour l’opérateur.
- Mesure de la HT : détecte les déclenchements et, comparée au bac à eau, mesure l’efficacité.
- Condensateur 470 nF / 2 kV : augmente l’énergie de décharge : tue le frelon au lieu de l’étourdir.
- Objet connecté (LoRaWAN) : suivi à distance de l’activité du frelon et de l’efficacité.

## Construction mécanique

Pour 3 harpes (cadre 60 × 60 cm, 11 fils par plan × 2 plans) : 72 isolateurs imprimés en 3D, 48 m de fil inox 0,5 mm, tasseaux bois 15 × 38 mm, câble souple 2G0,75, vernis marin, plaques « Danger Haute Tension » et connecteurs étanches. Comptez ~14 étapes et environ 3 jours (séchage du vernis compris).

## Électronique

Chaîne d’alimentation : panneau solaire → 2 convertisseurs DC/DC (2,4 V pour le booster, 5 V pour l’électronique) → booster 2 kV, complété du condensateur 470 nF/2 kV. Sécurité opérateur : coupure rapide de la HT à l’arrêt (relais, thyristor ou MOSFET/IGBT) et protection du condensateur de sortie contre les courts-circuits.

Attention au panneau solaire : un module de 25 × 25 cm ne délivre pas 50 W mais tout au plus ~10 W ; il faut le surdimensionner (40 W minimum), la puissance pouvant tomber à ~20 % par temps couvert. En option, l’objet connecté (ESP32 LORA32 V3, LoRaWAN, portée gateway ≈ 2,5 km) mesure la HT, la tension solaire, les alimentations et la température, et compte les électrocutions — pour suivre l’activité du frelon et l’efficacité réelle, sans se déplacer.

# 4. Précautions d’installation

⚠ Ne jamais installer une harpe près d’une ruche ou ruchette contenant un essaim artificiel récent. La reine vierge n’a pas encore fait son vol de fécondation et son envergure est comparable à celle du frelon : elle risquerait d’être électrocutée, condamnant la colonie.

- Placement : une harpe pour 5 ruches, aux extrémités et perpendiculaire à l’alignement ; parallèle au flanc des ruches ; un couloir de grillage à ~1 m devant peut orienter le vol des frelons ; entretenir régulièrement et signaler la zone (« Danger Haute Tension »).
- Le choix du bac est critique : retour d’expérience (oct. 2025) : eau pure → ~50 abeilles noyées dès le lendemain ; huile → ~10 abeilles engluées ; eau + liquide vaisselle non parfumé (savon glycériné) recommandé, qui limite fortement — sans supprimer totalement — les captures d’abeilles. Ne pas placer la harpe sur le passage des abeilles.

# 5. Résultats de capture (Beaumont, octobre 2025)

Contexte : en octobre 2024, l’infestation était très forte (une colonie détruite le 8 novembre malgré la destruction d’un nid à 100 m) ; en 2025, la pression restait significative (~60 frelons/semaine sur 2 pièges). Le plan national positionne la harpe en complément des muselières, avec disparition du stress des colonies ~8 jours après la pose et une efficacité pouvant atteindre 200 frelons/jour.

Date | Période (j) | Pièges | Harpes | Abeilles

07 oct — Installation des harpes
07 oct | 7 | 64 | n/a | n/a
11 oct | 4 | 20 | 9 | n/a
13 oct | 2 | 36 | 17 | 224
06 nov | 24 | 44 | 26 | 258

06 nov — Intervention : destruction d’un nid à 100 m

En un mois, 216 frelons capturés ; sur cette période les pièges en ont pris environ deux fois plus que les harpes — mais le panneau de 12 W, sous-dimensionné, laissait les harpes à l’arrêt par temps couvert (efficacité non maximale).

## Enseignements & suite à donner

- La harpe centrale : capture le plus de frelons et le moins d’abeilles : c’est la meilleure position.
- Capture d’abeilles : 128 abeilles sur la seule harpe de gauche, trop proche de l’entrée (pic le 6/11, possiblement une mortalité d’abeilles d’été rendue visible). Une fondatrice a été capturée (corps 35 mm, envergure 40 mm).
- Suite : ajouter les dispositifs de sécurité et terminer l’objet connecté.

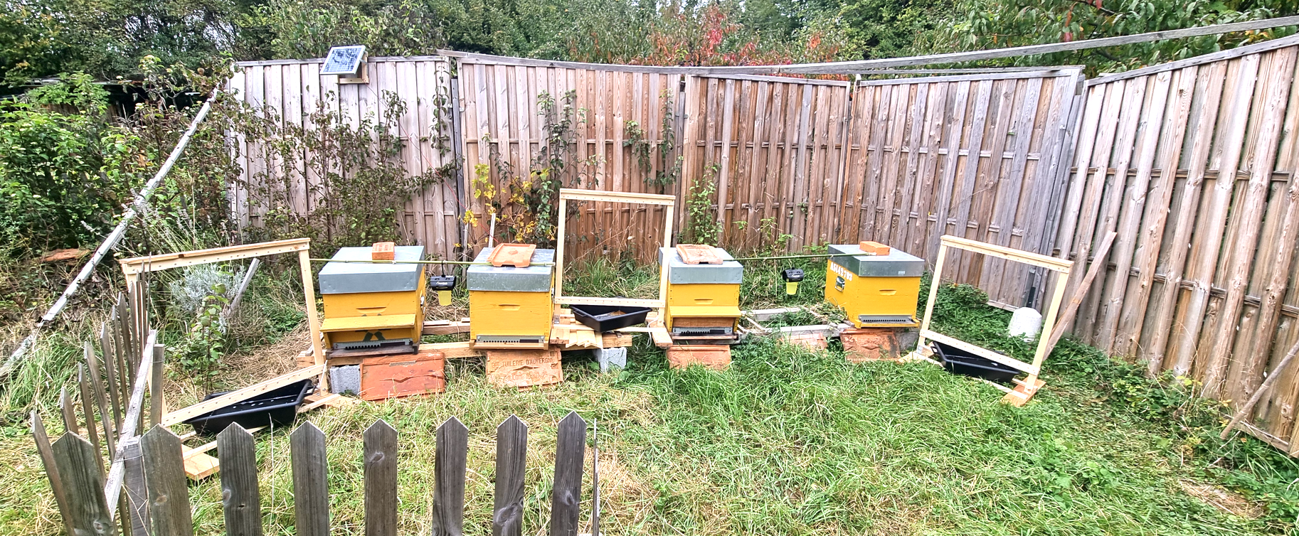
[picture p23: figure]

Vue d’ensemble de l’installation

En résumé : la harpe est un moyen de lutte efficace et économique en autoconstruction, à condition de soigner l’isolation, de surdimensionner l’alimentation solaire et de bien positionner les harpes pour limiter la capture d’abeilles. Construire soi-même fait économiser plus de 50 % du coût d’un kit 3 harpes « clés en main ».

Pour accéder au dossier de fabrication complet : https://github.com/jn-simonnet/Harpe_frelons

La harpe anti-frelons asiatiques — © J.-N. Simonnet, 2026 Page 3 / 3

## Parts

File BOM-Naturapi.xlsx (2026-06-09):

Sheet: BOM JNS
Article | Fournisseur | PU (€) | Qty | TOTAL (€) | URL
Construction harpes
Botte de 8 tasseaux en sapin brut L. 2,40 m - Section 38 x 15 mm | Brico Dépôt | 15.90 | 1 | 15.90 | https://www.bricodepot.fr/lempdes-clermont-ferrand/botte-de-8-tasseaux-en-sapin-brut-l-240-m-section-38-x-15-mm/prod63236/
Vernis marin bois incolore mat 0,25L Syntilor | Castorama | 18.90 | 1 | 18.90 | https://www.castorama.fr/vernis-marin-bois-incolore-mat-0-25l-syntilor/3239911261096_CAFR.prd
Auge en plastique tous travaux - 10 L | Brico Dépôt | 2.99 | 3 | 8.97 | https://www.bricodepot.fr/lempdes-clermont-ferrand/auge-en-plastique-tous-travaux-10-l/prod382/ref281622/
Équerre d'assemblage 60x60x40 mm Ép. 1,5 à 2,5 mm selon les modèles - Simpson | Brico Dépôt | 0.89 | 6 | 5.34 | https://www.bricodepot.fr/lempdes-clermont-ferrand/equerre-dassemblage60x60x40-mm-ep-15-a-25mm-selon-les-modeles/prod1707/ref172596/
Boite 300 vis à bois PowerFast II 4 x 40 mm tête fraisée, zingué blanc | Brico Dépôt | 15.90 | 1 | 15.90 | https://www.bricodepot.fr/lempdes-clermont-ferrand/boite-300-vis-a-bois-powerfast-ii-4-x-40-mm-tete-fraisee-zingue-blanc-filetage-total/prod87960/ref120577/
Vis 4 mm x 40mm | Castorama |  | 192 | 10.00
Vis 4x20 | Castorama |  | 48 | 10.00
Isolateurs plastique 24 par harpe |  | 1.00 | 72 | 72.00 | Fabrication additive selon design J.N. Simonnet
Barrette plastique pour fabrication de harpe à frelon KEMP, La paire | Naturapi | 17.00 | 3 |  | https://www.naturapi.com/barrettes-pour-fabrication-de-harpe-a-frelon-kemp-la-paire.html
Fil inox, la bobine de 250g (0,45 mm) | Naturapi | 4.90 | 1 | 4.90 | https://www.naturapi.com/fil-inox-recuit-diam-inox-1-4301-304-bobine-de-250g.html
Electronique
Boîte de dérivation extérieure avec 7 passe-câbles Diall | Castorama | 2.59 | 3 | 7.77 | https://www.castorama.fr/boite-de-derivation-exterieure-avec-7-passe-cables-et-systeme-de-verrouillage-integre-diall-100x-100-x-55-mm/3663602794141_CAFR.prd
Module booster DC3.7V jusqu'à 1800V, impulsion d'arc DC4.2V jusqu'à 2000V DC (5 pièces) | AliExpress | 15.47 | 1 | 15.47 | https://fr.aliexpress.com/item/1005008737696511.html
Panneau solaire Portable 50W, DC 18V | AliExpress | 35.00 | 1 | 35.00 | https://fr.aliexpress.com/item/1005008640163222.html
Condensateur à couche mince haute tension non inductif, 0.47UF, 2000V DC | AliExpress | 8.59 | 1 | 8.59 | https://fr.aliexpress.com/item/1005007876406707.html
Support panneau solaire
Poteau en bois Blooma vert 4,5 x 4,5 x h.180 cm | Castorama | 5.19 | 1 | 5.19 | https://www.castorama.fr/poteau-en-bois-blooma-vert-4-5-x-4-5-x-h-180-cm/3663602433187_CAFR.prd
Base poteau à enfoncer galva 4,5 x 4,5 cm | Castorama | 7.99 | 1 | 7.99 | https://www.castorama.fr/base-poteau-a-enfoncer-galva-4-5-x-4-5-cm/3663602943228_CAFR.prd
Planche de coffrage brut en sapin et epicéa 27X150X3000 mm | Castorama | 5.60 | 3 | 16.80 | https://www.castorama.fr/planche-de-coffrage-brut-en-sapin-et-epicea-27x150x3000-mm/5059340854168_CAFR.prd
TOTAL |  |  |  | 241.92

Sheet: Découpe tasseaux harpes
Pour 1 harpe :
Fixation isolateurs | 4 | 700
Pieds | 2 | 700
Montants | 2 | 800
Etais | 2 | 300
Longueurs de 2,40m
Tasseau # | Usage | L1 | L2 | L3 | Total
 |  | (mm) | (mm) | (mm) | (mm)
1 | Cadre 1 | 700 | 700 | 800 | 2200
2 | Cadre 1 | 700 | 700 | 800 | 2200
3 | Cadre 2 | 700 | 700 | 800 | 2200
4 | Cadre 2 | 700 | 700 | 800 | 2200
5 | Cadre 3 | 700 | 700 | 800 | 2200
6 | Cadre 3 | 700 | 700 | 800 | 2200
7 | Piétements | 700 | 700 | 700 | 2100
8 | Piétements | 700 | 700 | 700 | 2100

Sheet: Choix panneaux solaires
Puissance (P) | Px | A | B | Nb | P/cellule | Surface (S) | P/S | Px/P | URL
(W) | (€) | (mm) | (mm) | cellulles | (W) | (m²) | (W/m²) | (€/W)
60 | 33.21 | 605 | 570 | 9 | 6.67 | 0.345 | 173.9886907 | 0.553 | https://fr.aliexpress.com/item/1005008035401494.html
50 | 25.76 | 790 | 400 | 6 | 8.33 | 0.316 | 158.2278481 | 0.515 | https://fr.aliexpress.com/item/1005008640163222.html
40 | 27.63 | 570 | 425 | 6 | 6.67 | 0.242 | 165.1186791 | 0.691 | https://fr.aliexpress.com/item/1005007924230655.html
20 | 34.79 | 360 | 330 | 4 | 5.00 | 0.119 | 168.3501684 | 1.740 | https://fr.aliexpress.com/item/1005004067696248.html
12 | 13.39 | 280 | 270 | 4 | 3.00 | 0.076 | 158.7301587 | 1.116 | https://fr.aliexpress.com/item/1005008198613878.html

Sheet: Support panneau solaire
 | SKU | PU (€) | Qty | Total | Casto allée
Poteau en bois Blooma vert 4,5 x 4,5 x h.180 cm | 3663602433187 | 5.19 | 1 | 5.19 | 402
Base poteau à enfoncer galva 4,5 x 4,5 cm | 3663602943228 | 7.99 | 1 |  | 402
Planche de coffrage brut en sapin et epicéa 27X150X3000 mm | 5059340854168 | 5.6 |  |  | 408
Pour un panneau solaire, support de 750x650
 | 625 | 625 | 625 | 625 | 250 | 250 | 3000
 | 625 | 625 | 625 | 625 | 500 |  | 3000
 | 625 | 625 | 625 | 625 | 500 |  | 3000
Base poteau à enfoncer galva 7 x 7 cm | 3663602943242 | 8.09 | 1 |  | 404
Poteau en bois Blooma vert 7 x 7 x h.180 cm | 3663602433200 | 7.339 | 11 |  | 404
 |  | 18.43494882
 |  | 33.69006753

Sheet: Support panneaux découpe bois
 | Elt. 1 | Elt. 2 | Elt. 3 | Elt. 4 | Elt 5 | Elt 6 | Elt7 | Elt8 | Reste | TOTAL
Pour 2 panneaux ensemble
Planche 27X150X3000 mm | 625 | 625 | 625 | 625 | 500 |  |  |  | 0 | 3000
 | travée | travée | travée | travée | 2 supp.
Planche 27X150X3000 mm | 600 | 150 | 150 | 600 | 500 | 300 | 300 | 300 | 100 | 3000
 | 2 assy | 2 supp. | 2 supp. | 2 assy | incliné | tablette | tablette | 2 assy
Planche 27X150X3000 mm | 625 | 625 | 625 | 625 | 500 |  |  |  | 0 | 3000
 | travée | travée | travée | travée | incliné
Panneau 1 et tablette
Planche 27X150X3000 mm | 625 | 625 | 625 | 625 | 500 |  |  |  | 0 | 3000
 | travée | travée | travée | travée | 2 supp.
Planche 27X150X3000 mm | 600 | 150 | 300 | 300 | 300 |  |  |  | 1350 | 3000
 | 2 assy | 2 supp. | tablette | tablette | 2 assy
Panneau 2
reste panneau 1 | 500 | 600 | 150 |  |  |  |  |  | 100 | 1350
 | 2 supp. | 2 assy | 2 supp.
Planche 27X150X3000 mm | 625 | 625 | 625 | 625 | 500 |  |  |  | 0 | 3000
 | travée | travée | travée | travée | incliné
 | Support panneau 1
 | Tablette en haut de poteau pour pluviomètre
 | Support panneau 2

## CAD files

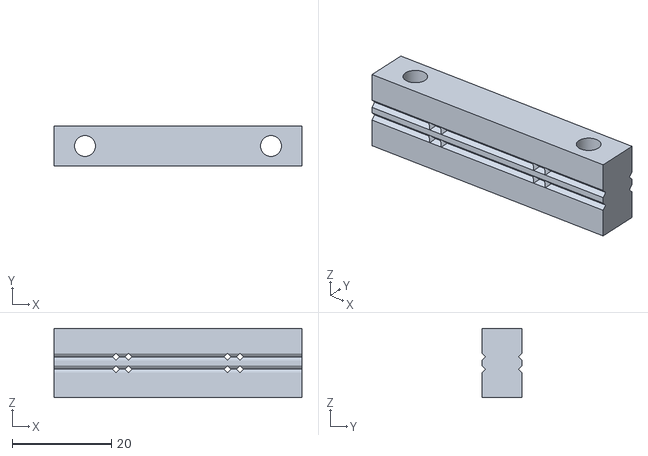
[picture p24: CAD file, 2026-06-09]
isolateur-arret.stl
50.0 x 8.00 x 14.0

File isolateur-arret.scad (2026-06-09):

/*
   Harpe anti-frelons asiatiques
   Isolateur à réaliser en PETG (durabilité aux UVs)
   
   Ces pièces permettent par juxtaposition d'obtenir une barre transversale isolante
   permettant le passage de fil inox diam. 0.5.
   Le pas entre fils voisins est de 25 mm (paramètre p ajustable à volonté).
   
   Les trous de passage sont à 12.5 mm (p/2) du bord de la pièce, ce qui permet
   d'obtenir un pas de 25 mm quand on juxtapose 2 pièces.
   
   Deux trous de vis de fixation permettent de visser ces pièces dans deux barres
   transversales servant de joues de support à l'ensemble des pièces.
*/
$fn=100;

He=14;  // Hauteur isolateur
Di=4.2; // Diamètre perçage de fixation, pour vis de 4x40
dt=1;   // Diamètre trou de passage fil inox
p=25;   // Pas des fils
e=8;    // Epaisseur pièce de fixation fils
a=2.5;  // Espacement des deux plans de fils
b=2.5;  // Espacement trous pour arrêt aux extrémités

h1=(He-a)/2; // hauteur premier plan de fils
h2=He-h1;    // hauteur 2e plan de fils
h3=h1/2;     // trous pour fixation fils plan du bas
h4=He-h3;    // trous pour fixation fils plan du haut

difference () {
  cube([2*p,e,He]);
  union() {
    // Trous de fixation
    translate([p/4,e/2,0])  cylinder(d=Di,h=He);
    translate([2*p-p/4,e/2,0])  cylinder(d=Di,h=He);
      
    // Trous pour passage fils
    //translate([p/2,0,He/3])  rotate([-90,0,0])  cylinder(d=dt,h=e);
    //translate([p/2,0,2*He/3])  rotate([-90,0,0])  cylinder(d=dt,h=e);
    //translate([2*p-p/2,0,He/3])  rotate([-90,0,0])  cylinder(d=dt,h=e);
    //translate([2*p-p/2,0,2*He/3])  rotate([-90,0,0])  cylinder(d=dt,h=e);
    translate([p/2,0,h1])  rotate([45,0,90])  translate([0,-dt/2,-dt/2])  cube([e,dt,dt]);
    translate([p/2,0,h2])  rotate([45,0,90])  translate([0,-dt/2,-dt/2])  cube([e,dt,dt]);
    translate([2*p-p/2,0,h1])  rotate([45,0,90])  translate([0,-dt/2,-dt/2])  cube([e,dt,dt]);
    translate([2*p-p/2,0,h2])  rotate([45,0,90])  translate([0,-dt/2,-dt/2])  cube([e,dt,dt]);;
    translate([0,0,h1])  rotate([45,0,0])  translate([0,-dt/2,-dt/2])  cube([2*p,dt,dt]);
    translate([0,0,h2])  rotate([45,0,0])  translate([0,-dt/2,-dt/2])  cube([2*p,dt,dt]);
    translate([0,e,h1])  rotate([45,0,0])  translate([0,-dt/2,-dt/2])  cube([2*p,dt,dt]);
    translate([0,e,h2])  rotate([45,0,0])  translate([0,-dt/2,-dt/2])  cube([2*p,dt,dt]);

    // trous fixation fils (pour extrémités)
    translate([p/2+b,0,h1])  rotate([45,0,90])  translate([0,-dt/2,-dt/2])  cube([e,dt,dt]);
    translate([p/2+b,0,h2])  rotate([45,0,90])  translate([0,-dt/2,-dt/2])  cube([e,dt,dt]);
    translate([2*p-p/2-b,0,h1])  rotate([45,0,90])  translate([0,-dt/2,-dt/2])  cube([e,dt,dt]);
    translate([2*p-p/2-b,0,h2])  rotate([45,0,90])  translate([0,-dt/2,-dt/2])  cube([e,dt,dt]);;
  }
}

//translate([0,0,He/3])  rotate([0,90,0])  cylinder(d=dt,h=2*p);
//translate([0,0,2*He/3])  rotate([0,90,0])  cylinder(d=dt,h=2*p);

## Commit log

2026-06-09 Version initiale : harpe anti-frelons (docs, présentation, modèles 3D, BOM, licence)
    [BOM-Naturapi.xlsx, isolateur-arret.scad, isolateur-arret.stl]
2026-06-18 Partie fabrication déplacée en fin de présentation
